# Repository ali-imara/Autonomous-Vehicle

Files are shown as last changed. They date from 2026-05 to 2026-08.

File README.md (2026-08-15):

# Autonomous Vehicle

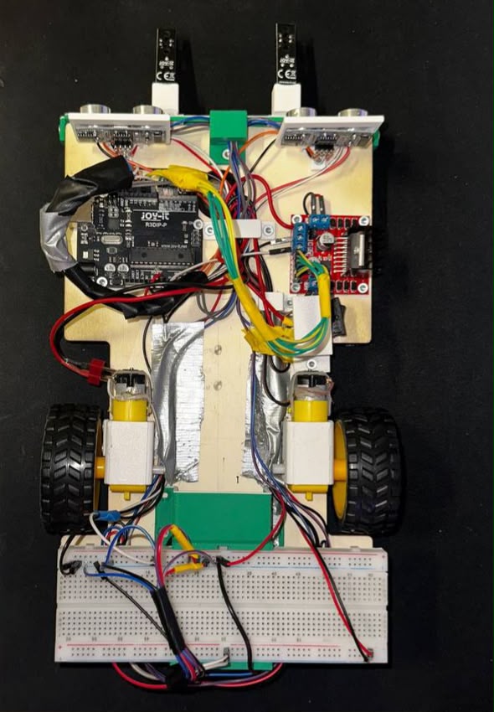
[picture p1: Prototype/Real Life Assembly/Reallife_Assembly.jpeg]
Project Overview


## Project Overview
This repository contains the engineering documentation, 3D mechanical designs, and control software for an autonomous prototype vehicle developed by Team D5. 

The primary focus of this project was to design, construct, and program a smart car capable of independent navigation and dynamic obstacle handling. The development process required the seamless integration of mechanical engineering, electronic hardware, and intelligent control algorithms using a comprehensive systems engineering methodology.

## Core Capabilities
The vehicle is designed to achieve the following autonomous objectives:
*   **Autonomous Navigation:** Follows a predefined track autonomously by utilizing dual infrared (IR) sensors to track the surrounding white surface and re-center on the black line.
*   **Early Obstacle Detection:** Recognizes obstructions in its path early by employing dual front-facing ultrasonic sensors.
*   **Dynamic Avoidance and Recovery:** Upon detecting an obstacle (≤ 18 cm), the vehicle executes an arc-based avoidance maneuver, safely bypasses the object, actively recovers the black line, and continues its route without manual intervention.
*   **Dual-Obstacle Handling:** As a special bonus objective, the system utilizes a persistent counter to track consecutive obstacles, triggering an automatic 180-degree spin to reverse course if the path is heavily blocked.

## Repository Structure
This repository is organized into the following directories to reflect the mechatronic development process:

*   📂 **`Arduino Code/`** 
    Contains the object-oriented C++ software, the finite state machine (FSM) control logic, and a technical README detailing the specific hardware pinouts and class architecture. 
*   📂 **`3D Design Parts/`** 
    Contains the SolidWorks part files and STEP files for the custom-designed chassis mounts, adjustable IR sensor slider, and component holders.
*   📂 **`Documentation/`**
    Contains the final engineering report, the project presentation, and task division documents.
*   📂 **`Prototype/`**
    Contains media and models from the physical build process, including the Tinkercad circuit simulation, circuit layouts, and real-life assembly photos.
*   📂 **`SYSML Diagrams/`**
    Contains the system modeling diagrams (Requirements, Activity, Sequence, etc.) used to map interactions between the sensors, Arduino, and motors prior to implementation.

## Project Team
**Team Members:**
*   Mohamed Awis (Team Leader)
*   Ali Abdelkhalek
*   Yassin Elhalawany

**Supervisors:** 
*   Prof. Dr. Stefan Henkler
*   Prof. Dr. Faezeh Pasandideh

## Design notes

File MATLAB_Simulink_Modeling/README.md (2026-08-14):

# MATLAB/Simulink Vehicle Modeling

This folder contains a MATLAB/Simulink extension of an autonomous
line-following vehicle project.

The simulation combines physical DC motor dynamics, differential-drive
vehicle kinematics, and a closed-loop line-following controller.

## DC Motor Model

The electrical motor dynamics are modeled as:

di/dt = (V - Ri - Keω) / L

The mechanical dynamics are:

dω/dt = (Kt i - bω - TL) / J

Motor torque is calculated using:

Tm = Kt i

Two motor models are used to represent the left and right drive wheels.

## Vehicle Model

Wheel angular velocities are converted into linear wheel velocities.

The differential-drive equations are:

v = (vR + vL) / 2

θ_dot = (vR - vL) / wheelDistance

Vehicle position is obtained from:

x_dot = v cos(θ)

y_dot = v sin(θ)

## Line-Following Controller

The lateral position reference is defined as:

y_ref = 0

The lateral error is:

e_y = y_ref - y

A feedback controller calculates the steering correction:

u = Ky e_y - Ktheta θ

The resulting motor voltage commands are:

V_R = Vbase + u

V_L = Vbase - u

Voltage saturation limits the motor commands to the available supply range.

## Validation

The DC motor model was first validated independently by comparing the
simulated current, torque, and angular velocity with analytical
steady-state and startup calculations.

The complete vehicle model was then tested with an initial lateral
offset. The controller successfully reduced the lateral position error
and drove the vehicle toward the reference line.

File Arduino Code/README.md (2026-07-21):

# D5 Autonomous Prototype Car Control Software
**Team D5 | Hochschule Hamm-Lippstadt**

## Overview
This folder contains the object-oriented C++ control software for the Team D5 autonomous prototype vehicle. The codebase allows the car to autonomously follow a track using infrared (IR) sensors, detect path obstructions early via dual ultrasonic sensors, and execute dynamic, arc-based avoidance maneuvers without manual intervention.

## Hardware Configuration
The vehicle is driven by an Arduino microcontroller and an L293D motor driver. The hardware pinout is defined in the code as follows:

| Component | Arduino Pin | Description |
| :--- | :--- | :--- |
| **Left Motor** | 9 (EN), 4 (IN1), 5 (IN2) | PWM speed control on pin 9 |
| **Right Motor** | 10 (EN), 6 (IN1), 7 (IN2) | PWM speed control on pin 10 |
| **Left IR Sensor** | 2 | Digital Input (LOW = White surface / HIGH = Black line) |
| **Right IR Sensor** | 3 | Digital Input (LOW = White surface / HIGH = Black line) |
| **Right Ultrasonic** | 8 (Trig), 11 (Echo) | Distance measurement |
| **Left Ultrasonic** | 12 (Trig), 13 (Echo) | Distance measurement |

## Software Architecture
The software is built using an Object-Oriented Programming (OOP) architecture to ensure modularity and readable control logic:
*   **Hardware Abstraction:** Custom `Motor`, `IRSensor`, and `UltrasonicSensor` classes abstract the low-level digital and analog pin manipulations.
*   **Core Controller (`Car`):** Manages the primary autonomous driving loop. It utilizes non-blocking timers (`millis()`) to continuously poll the ultrasonic sensors every 30 milliseconds without interrupting real-time line-following adjustments.
*   **Finite State Machine (FSM):** Obstacle avoidance is managed by the `AvoidState` enumeration. Upon detecting an object within the 18 cm threshold, the FSM transitions the vehicle through a sequence of specific states (`STOP_BEFORE_OBSTACLE`, `LEFT_ARC_AROUND`, `RIGHT_ARC_BACK`, `RECOVER_LINE`) to navigate safely.

## Key Features
*   **Surface-Based Line Following:** The vehicle continuously reads the white track surface. If either IR sensor detects the black line, the software instantly adjusts the differential motor speeds to re-center the vehicle.
*   **Smooth Arc Avoidance:** Instead of sharp, blocky turns, the vehicle bypasses obstacles using a calculated left arc, followed by a wider right arc to smoothly sweep back toward the original path.
*   **Dynamic Collision Prevention:** During an avoidance maneuver, if the lateral distance to an obstacle drops below 10 cm, the system dynamically sharpens the turning radius to prevent side-swiping.
*   **Bonus Objective (180-Degree Turn):** The system tracks consecutive obstacle detections. If a second obstacle is detected within a two-second cooldown window, the FSM triggers a `TURN_180` state. This bypasses standard avoidance, spins the vehicle completely around, and automatically recovers the line in the opposite direction. 

> **Safety Note:** Place the vehicle on the track prior to powering it on. The `setup()` function features a built-in 2-second delay (`while (millis() - startTime < 2000)`) to allow the user to clear their hands away before the drive motors engage.

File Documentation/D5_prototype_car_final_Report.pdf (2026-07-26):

1 | P a g e

## Prototyping Project Team D5

## 1. Introduction and Objectives

The development of autonomous vehicles is an interdisciplinary challenge that requires the seamless integration of mechanical engineering, electronic hardware, and intelligent control algorithms. This report details the engineering process of an autonomous prototype vehicle developed by Team D5 at Hochschule Hamm-Lippstadt. The primary focus of this project was to design, construct, and program a smart car capable of independent navigation and dynamic obstacle handling.

The core objectives of the project were defined as follows:

- Autonomous Navigation: The vehicle must successfully follow a predefined path autonomously using infrared (IR) sensor feedback.
- Early Obstacle Detection: The system must recognize obstructions in its path early by employing ultrasonic sensors.
- Dynamic Avoidance and Recovery: Upon detecting an obstacle, the vehicle must execute an avoidance maneuver, recover the line, and continue its operation without manual control.

To achieve these objectives, the project utilized a comprehensive systems engineering methodology. This approach progressed from initial SysML modeling and simulated testing to 3D mechanical design, software implementation, and iterative physical validation.

## 2. System Design and Engineering Approach

The autonomous vehicle was developed using an integrated mechatronic design process covering requirements, system modeling, mechanical design, electronics, control software, simulation, and physical validation. The main objectives were autonomous black-line following, obstacle detection and avoidance, line reacquisition, and stable vehicle motion.

### 2.1 System Modeling

Requirements, use case, activity, sequence, and package diagrams were created to describe the system from complementary viewpoints. The requirements diagram defined and traced the main functions to the corresponding hardware, while the activity diagram described the operational logic. The remaining diagrams supported functional interaction, system organization, and component communication.

The requirements model decomposed the overall autonomous-driving objective into line detection, obstacle detection, motion control, speed optimization, and obstacle avoidance. Two infrared sensors were assigned to line tracking, two ultrasonic sensors to obstacle detection, and the motor-control subsystem to the two drive motors. This provided clear traceability between system requirements and physical implementation.

### 2.2 Engineering Implementation

The activity model defined the main control sequence: initialize sensors, read sensor data, follow the line, detect an obstacle, execute an avoidance maneuver, reacquire the line, and resume normal operation. This logic was implemented in software using modular classes for the motors, infrared sensors, ultrasonic sensors, and vehicle controller, together with explicit states for obstacle handling and recovery.

Mechanical development was performed in SolidWorks using a component-by-component approach before assembling the complete vehicle model. This allowed the positions of the motors, wheels, sensors, controller, and supporting parts to be checked before physical integration. The design was refined iteratively because sensor placement, vehicle geometry, motor response, and control parameters directly affected overall performance.

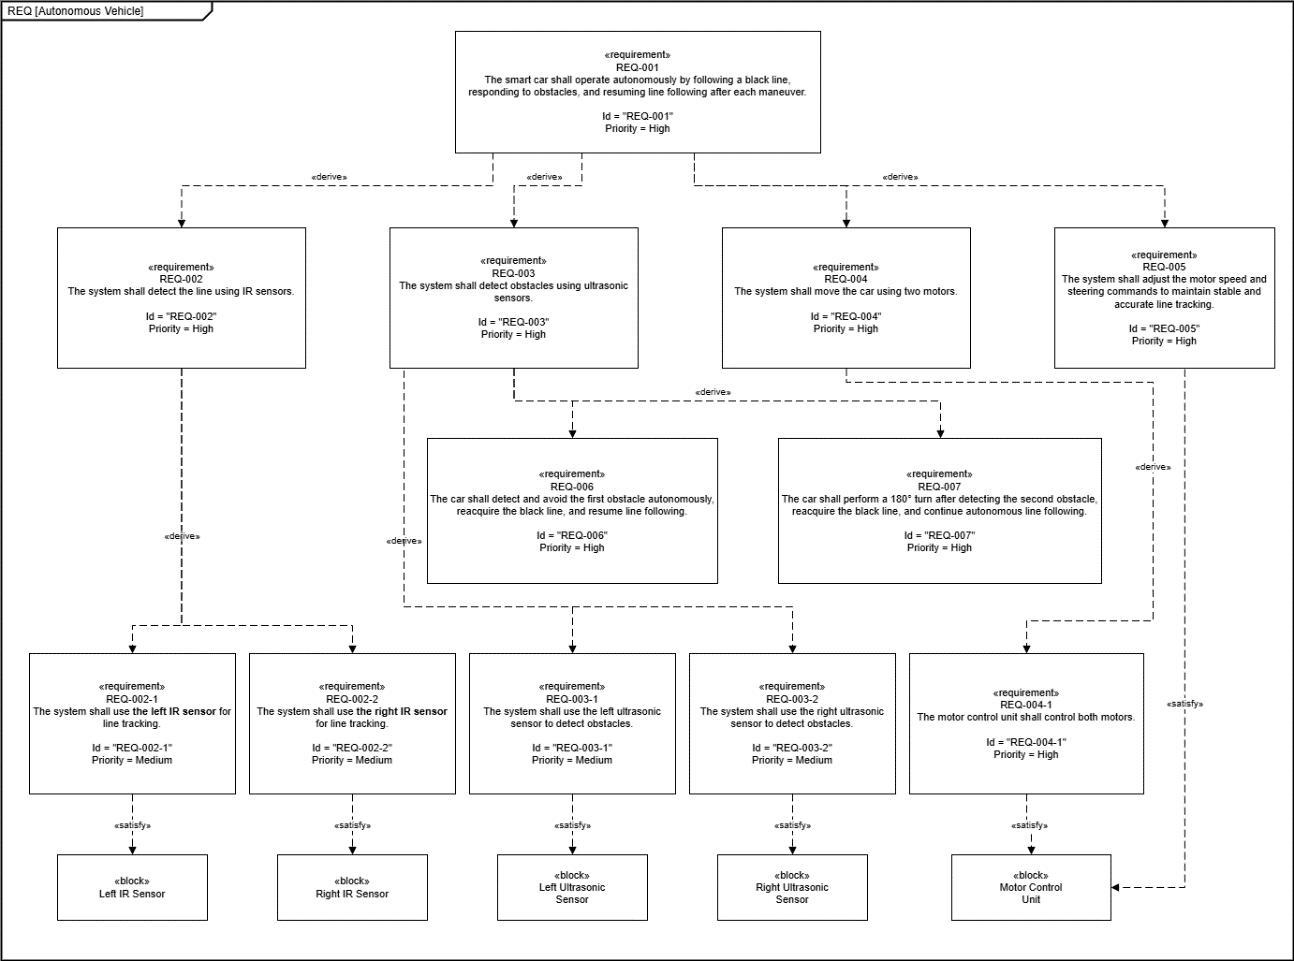
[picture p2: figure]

2 | P a g e

Fig. 1. Requirements model linking the autonomous-driving objectives to line sensing, obstacle sensing, motor control, and speed control.

## 3. Hardware and Software Implementation

### 3.1 Hardware Integration

The autonomous prototype car was controlled by an Arduino-based microcontroller. Its main hardware components included a breadboard, two motor-driver units, two IR sensors, two ultrasonic sensors, and a battery. The motor drivers controlled the speed and direction of the left and right motors, while the breadboard supported the electrical connections and power distribution.

The two IR sensors were installed at the front and close to the ground to distinguish
between the black line and the white track surface. The ultrasonic sensors were also positioned at the front to measure the distance to obstacles. Using two ultrasonic sensors increased the detection area and allowed objects approaching either side of the car to be recognized.

Custom component holders were designed using SolidWorks. Their positions were selected according to the function of each component and the available space on the chassis. The holders secured the sensors while allowing their positions to be adjusted. This arrangement also improved cable management: each wire was routed toward its corresponding component, reducing tangled or overlapping connections and making the electrical system easier to assemble, inspect, and troubleshoot.

### 3.2 Software Design and Control Logic

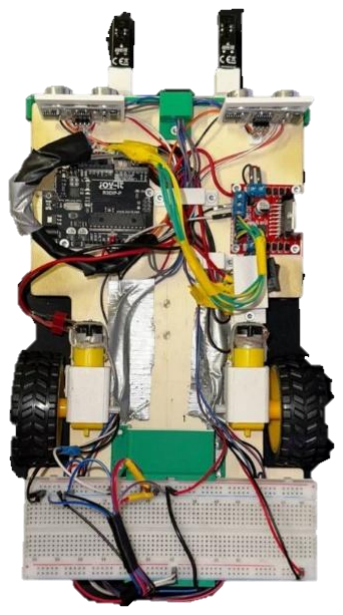
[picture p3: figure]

The vehicle’s control software was developed in C++ utilizing an object-oriented architecture to ensure modularity and ease of troubleshooting. Dedicated classes (Motor, IRSensor, and UltrasonicSensor) were constructed to abstract the low-level pin manipulations and standardize the interface between the hardware and the main control logic.

3 | P a g e

The core autonomous loop operates on a non-blocking framework, utilizing the microcontroller's internal timer (millis()) rather than standard delay functions. This allows the system to continuously poll the ultrasonic sensors at 30-millisecond intervals without interrupting the real-time line-following adjustments.

During standard operation, the Car class governs navigation. The system reads the track surface via the dual IR sensors; when both detect the white surface, the vehicle drives forward. If one sensor detects the black line, the software dynamically adjusts the differential motor speeds to re-center the vehicle, correcting its trajectory.

To handle obstructions, the software implements a Finite State Machine (FSM) controlled by the AvoidState enumeration. When the ultrasonic sensors detect an object within the 18 cm threshold, the system transitions from the IDLE state into an avoidance sequence:

- STOP_BEFORE_OBSTACLE: Halts the DC motors to prevent collision.
- LEFT_ARC_AROUND & RIGHT_ARC_BACK: Executes carefully timed, differential motor speeds to bypass the object and sweep back toward the original path. A dynamic distance check is integrated here; if the lateral distance to the object drops below 10 cm, the system temporarily sharpens the turn radius to prevent side-swiping.
- Line Recovery (SEARCH_LINE & RECOVER_LINE): Instead of relying solely on dead reckoning, the FSM actively polls the IR sensors while spinning. The loop breaks at the exact millisecond a sensor touches the black line, pausing briefly to let the chassis settle before resuming forward motion.

enum AvoidState {

IDLE, STOP_BEFORE_OBSTACLE, LEFT_ARC_AROUND, RIGHT_ARC_BACK, SEARCH_LINE, RECOVER_LINE, TURN_180 };

void handleObstacleAvoidance() {

unsigned long elapsed = millis() - avoidTimer;

switch (avoidState) {

case STOP_BEFORE_OBSTACLE:

stop();

if (elapsed > STOP_TIME) {

avoidState = LEFT_ARC_AROUND;

avoidTimer = millis();

}

break;

case LEFT_ARC_AROUND:

if (rightSonar.getDistance() > 0 &&

rightSonar.getDistance() < 10) spinLeft();

else arcLeft();

if (elapsed > LEFT_ARC_TIME) {

avoidState = RIGHT_ARC_BACK;

avoidTimer = millis();

}

break;

case RIGHT_ARC_BACK:

arcRight();

if (elapsed > 150 && blackLineDetected()) {

delay(250);

spinLeft();

while (!blackLineDetected()) {} // Spin

stop();

avoidState = RECOVER_LINE;

}

break;

case TURN_180:

leftMotor.forward(0); rightMotor.forward(65);

if (elapsed > 1400 && blackLineDetected()) {

stop();

avoidState = RECOVER_LINE;

isTurning = false;

}

break;

}

}

4 | P a g e

Additionally, to fulfill a bonus objective, a dual-obstacle tracking mechanism was implemented. The software maintains a persistent counter for detected obstacles. To ensure a single object is not counted multiple times during a maneuver, a two-second cooldown is enforced between valid detections. Once the system registers a second distinct obstacle, it triggers a TURN_180 state, bypassing the standard avoidance arc to spin the vehicle completely around and automatically recover the line in the opposite direction.

## 4. Simulation and Testing Results

### 4.1 Circuit Simulation

The electronic architecture was first modeled in TinkerCAD to verify the main connections and controller interfaces before complete physical testing. The model included an Arduino Uno, an L293D motor driver, two DC motors, two infrared sensors, two HC-SR04 ultrasonic sensors, and the power circuitry.

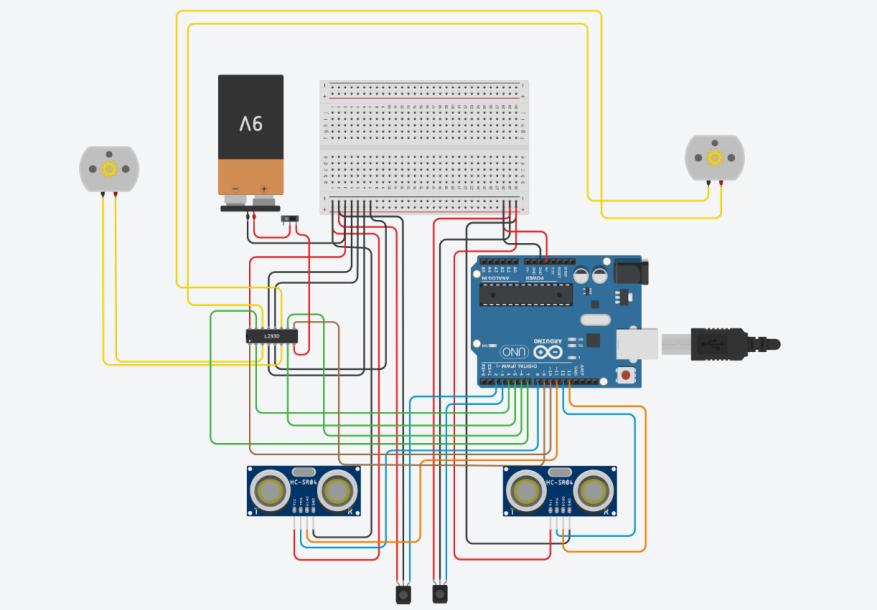
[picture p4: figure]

Fig. 2. TinkerCAD circuit model is used to verify the controller, sensors, motor driver, and drive motors.

Parameter | Value | Purpose
Battery supply | 9 V | External circuit supply
Controller / sensor logic | 5 V | Arduino and sensor operating level
Obstacle detection threshold | ≤ 18 cm | Triggers avoidance sequence
Close-obstacle correction | < 10 cm | Applies stronger steering correction

Table 1. Key electrical and distance parameters used in the implemented system.

### 4.2 Physical Testing

Testing was divided into two main tasks. In Task 1, the vehicle was required to follow the black line autonomously using the two infrared sensors. Motor speed and steering parameters were tuned through repeated runs to improve tracking stability and reduce excessive oscillation. Vehicle speed was determined experimentally from travelled distance and elapsed time.

In Task 2, an obstacle was placed in the vehicle path. When the measured distance reached the defined threshold, normal line following was interrupted and the vehicle executed a programmed avoidance sequence: stop, move

5 | P a g e

around the obstacle, return toward the original path, detect the black line again, and resume line following. A dedicated search-and-recovery state was included if the line was not immediately required.

The evaluation therefore focused on three performance indicators: line-following stability, vehicle speed, and successful obstacle avoidance followed by line reacquisition. Together, circuit simulation and physical testing provided progressive validation from subsystem integration to complete autonomous operation.

## 5. Challenges Encountered and Solutions

### 5.1 IR Sensor Position and Line-Following Method

The first challenge resulted from the mechanical design of the IR sensor holders. The holders were mounted inside an adjustable slider at the front of the chassis. Although the slider allowed their horizontal positions to be changed, it placed the sensors slightly too far above the ground. This made it difficult to position both sensors directly over the black line and obtain consistent readings.

To solve this problem, the control method was changed from following the black line directly to following the surrounding white surface. When both sensors detect white, the car moves forward with the black line centred between them. If one sensor reaches the black line, the program corrects the direction. This method improved stability and allowed the car to move faster when properly centered.

### 5.2 Speed and Detection-Distance Optimization

Choosing an appropriate driving speed was another challenge. A high speed produced good performance on straight sections, but the car sometimes left the track during sharp turns because the system could not correct its direction quickly enough. Different motor speeds were therefore tested on straight sections, normal curves, and sharp turns. The final values provided a suitable balance between speed and steering response.

The ultrasonic detection distance also required calibration. A large range caused the car to react to nearby walls or people beside the track, whereas a very short range caused late detection and left insufficient space for avoidance. After repeated testing, the distance was set to 18 cm. This reduced false detections while still providing enough space to begin the avoidance maneuver. A sharper correction was added when the distance fell below 10 cm.

### 5.3 Obstacle Avoidance and Line Recovery

Several avoidance methods were tested. One early approach used a sequence of timed left and right movements, while another produced a V-shaped path. These methods involved sharp direction changes and were inconsistent because small differences in motor speed, starting position, and battery level affected the path. The car could therefore collide with the obstacle while passing it or while returning to the line.

The final solution used a smoother arc-based maneuver. The car stops, follows a left arc around the obstacle, and then follows a longer right arc toward the track. Different speeds are applied to the two motors to form each curve. When the line is detected again, the car crosses it slightly and rotates until the correct position is recovered.

These improvements were achieved through continuous testing and observation. Each result was analyzed to determine whether the problem originated from the mechanical design, sensor configuration, motor speed, or software logic. This iterative process significantly improved the reliability and consistency of the prototype.

6 | P a g e

## 6. Conclusions and Future Improvements

### 6.1 Conclusions

The project successfully yielded a fully functional autonomous prototype vehicle by integrating a custom 3D-printed mechanical structure, sensor arrays, an Arduino logic controller, and motor drivers into a single cohesive unit. Through structured system engineering and continuous testing, the initial theoretical models were effectively translated into a reliable physical system.

A primary learning outcome of this project was understanding the critical interplay between mechanical component placement, software logic, and speed optimization. Physical testing directly influenced the final vehicle behaviour; for instance, evaluation results prompted a shift in the line-following concept and refined the timing sequence for the arc-based obstacle avoidance maneuvers. Ultimately, the vehicle consistently demonstrated the ability to track a path, dynamically maneuver around obstacles, and recover its route autonomously.

### 6.2 Future Improvements

While the current prototype meets all primary project requirements, several areas have been identified for future enhancement to increase the vehicle's speed, precision, and overall reliability:

- PID Control Implementation: Upgrading the steering logic to a Proportional-Integral-Derivative (PID) controller would allow for smoother trajectory corrections and reduce oscillations during active line following.
- Expanded Sensor Array: Incorporating additional IR sensors would improve surface resolution, facilitating better and faster line recovery after an avoidance maneuver.
- Hardware Upgrades: Integrating an enhanced motor control driver would provide finer speed regulation and improved handling of the DC motors.
- Custom Printed Circuit Board (PCB): Replacing the prototype breadboard with a custom-specified PCB would significantly improve wiring reliability, reduce electrical noise, and condense the electronic footprint of the project.

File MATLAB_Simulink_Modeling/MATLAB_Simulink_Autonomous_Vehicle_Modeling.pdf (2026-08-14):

# MATLAB/Simulink Modeling

Mathematical Model of the Differential-Drive Vehicle and Line-Following Controller:

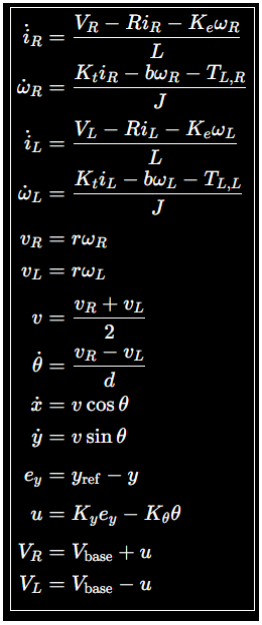
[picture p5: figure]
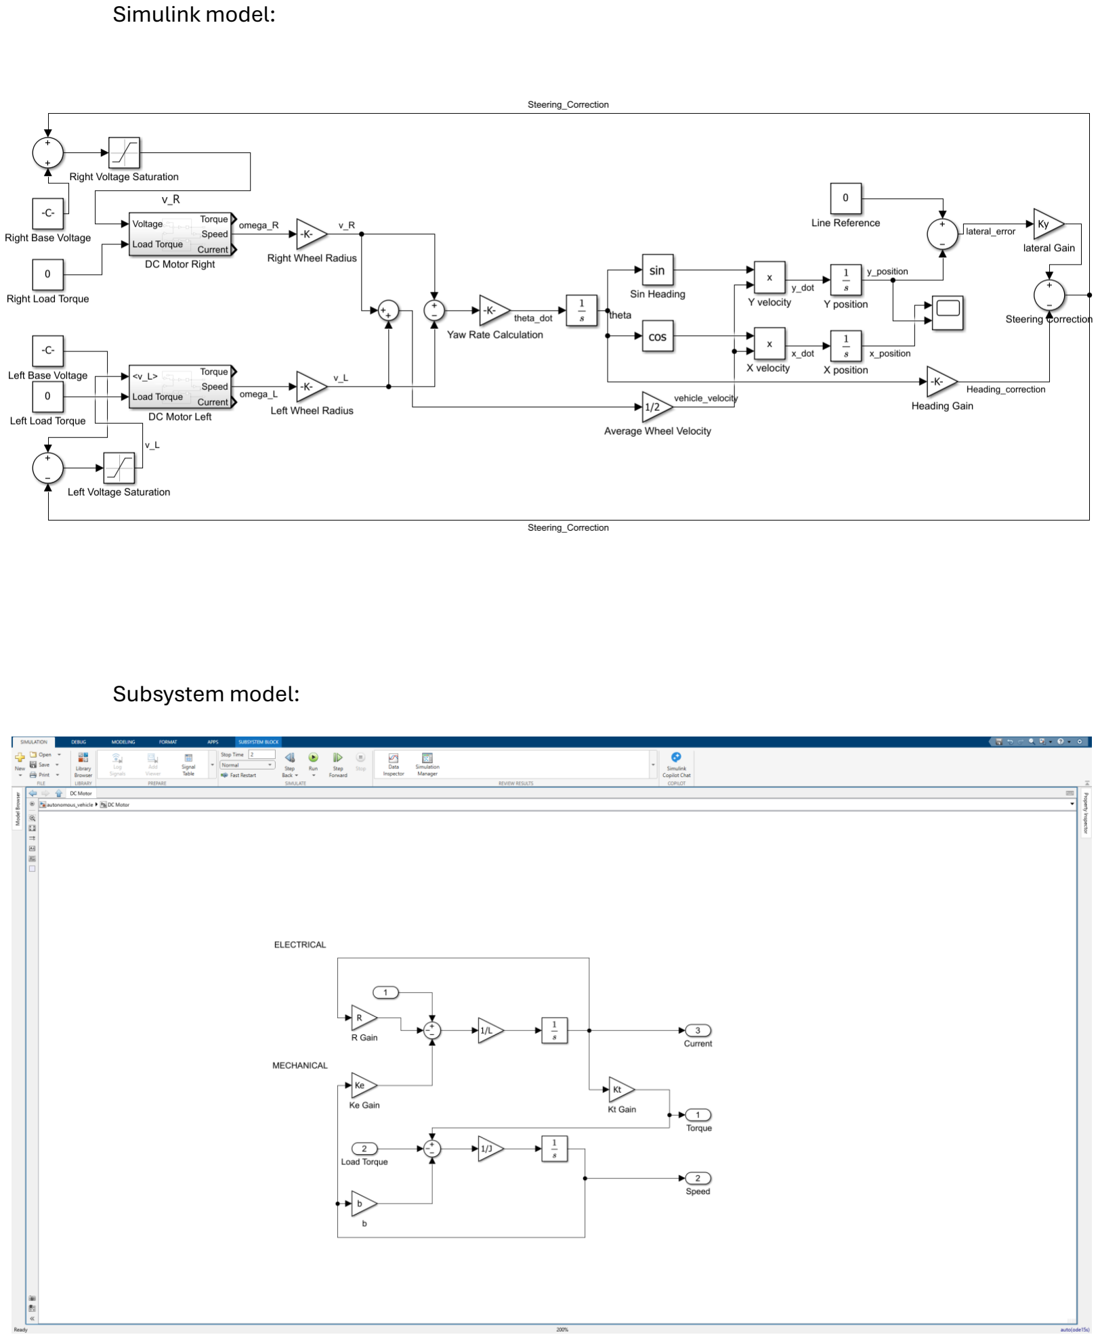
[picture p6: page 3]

Simulink model:

Subsystem model:

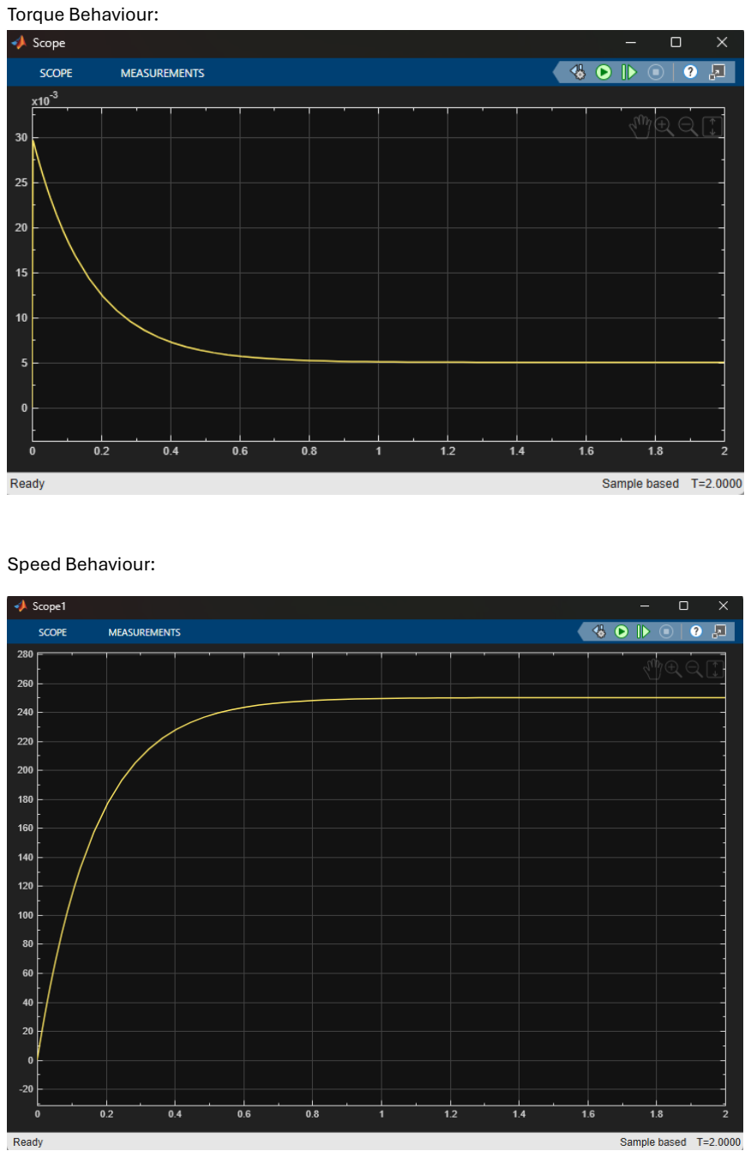
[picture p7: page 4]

Torque Behaviour:

Speed Behaviour:

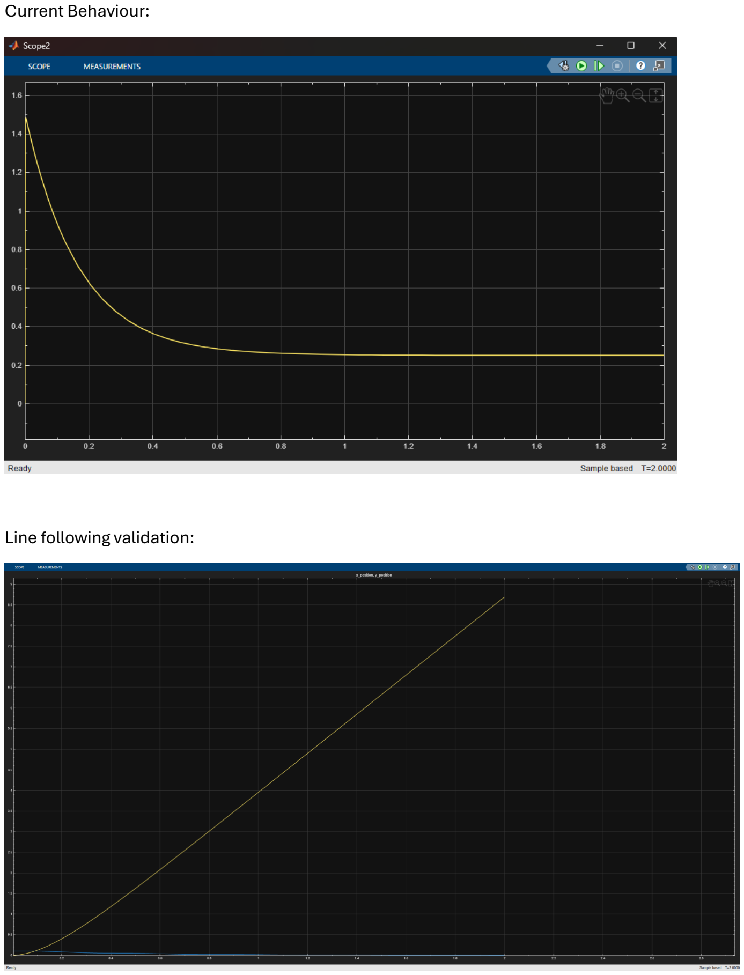
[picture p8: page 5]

Current Behaviour:

Line following validation:

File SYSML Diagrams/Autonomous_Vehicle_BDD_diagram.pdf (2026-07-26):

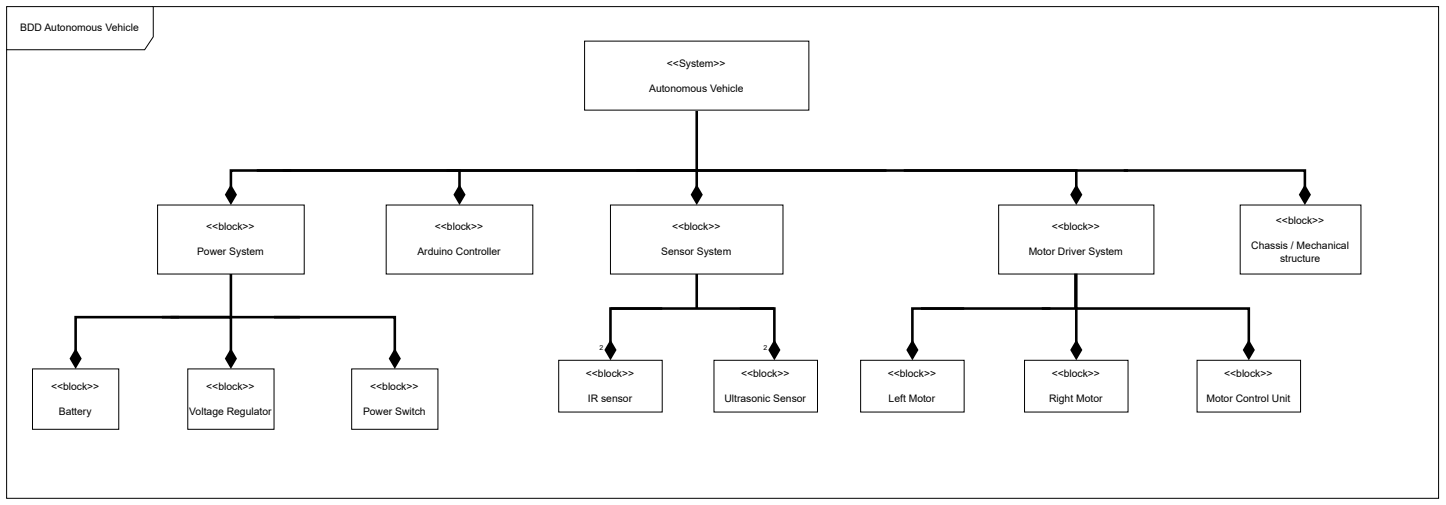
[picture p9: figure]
<<System>>; Autonomous Vehicle; <<block>>; Power System; Arduino Controller; Sensor System; Motor Driver System; Chassis / Mechanical structure; Battery; Voltage Regulator; Power Switch; IR sensor; Ultrasonic Sensor; Left Motor; Right Motor; BDD Autonomous Vehicle; Motor Control Unit

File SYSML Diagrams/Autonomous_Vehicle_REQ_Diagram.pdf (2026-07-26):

REQ [Autonomous Vehicle]

«requirement»
REQ-001
The smart car shall operate autonomously by following a black line, responding to obstacles, and resuming line following after each maneuver.

Id = "REQ-001"
Priority = High

«requirement»
REQ-002
The system shall detect the line using IR sensors.

Id = "REQ-002"
Priority = High

«requirement»
REQ-003
The system shall detect obstacles using ultrasonic sensors.

Id = "REQ-003"
Priority = High

«requirement»
REQ-004
The system shall move the car using two motors.

Id = "REQ-004"
Priority = High

«requirement»
REQ-005
The system shall adjust the motor speed and steering commands to maintain stable and accurate line tracking.

Id = "REQ-005"
Priority = High

«requirement»
REQ-006
The car shall detect and avoid the first obstacle autonomously, reacquire the black line, and resume line following.

Id = "REQ-006"
Priority = High

«requirement»
REQ-007
The car shall perform a 180° turn after detecting the second obstacle, reacquire the black line, and continue autonomous line following.

Id = "REQ-007"
Priority = High

«requirement»
REQ-002-1
The system shall use the left IR sensor for line tracking.

Id = "REQ-002-1"
Priority = Medium

«requirement»
REQ-002-2
The system shall use the right IR sensor for line tracking.

Id = "REQ-002-2"
Priority = Medium

«requirement»
REQ-003-1
The system shall use the left ultrasonic sensor to detect obstacles.

Id = "REQ-003-1"
Priority = Medium

«requirement»
REQ-003-2
The system shall use the right ultrasonic sensor to detect obstacles.

Id = "REQ-003-2"
Priority = Medium

«requirement»
REQ-004-1
The motor control unit shall control both motors.

Id = "REQ-004-1"
Priority = High

«block»
Left IR Sensor

«block»
Right IR Sensor

«block»
Left Ultrasonic
Sensor

«block»
Right Ultrasonic
Sensor

«block»
Motor Control
Unit
«derive» | «derive» | «derive»
«derive» | «derive»

«derive»

«derive»

«satisfy» | «satisfy» | «satisfy» | «satisfy» | «satisfy»

«satisfy»

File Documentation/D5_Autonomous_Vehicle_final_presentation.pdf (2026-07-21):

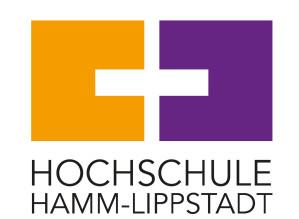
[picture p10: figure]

# Autonomous Prototype Car Project

## (Team D5)

## Team members:

Ali Abdelkhalek
Mohamed Awis
Yassin Elhalawany

## Supervisors:

Prof/ Dr Stefan Henkler
Prof/ Dr Faezeh Pasandideh

# Project Overview

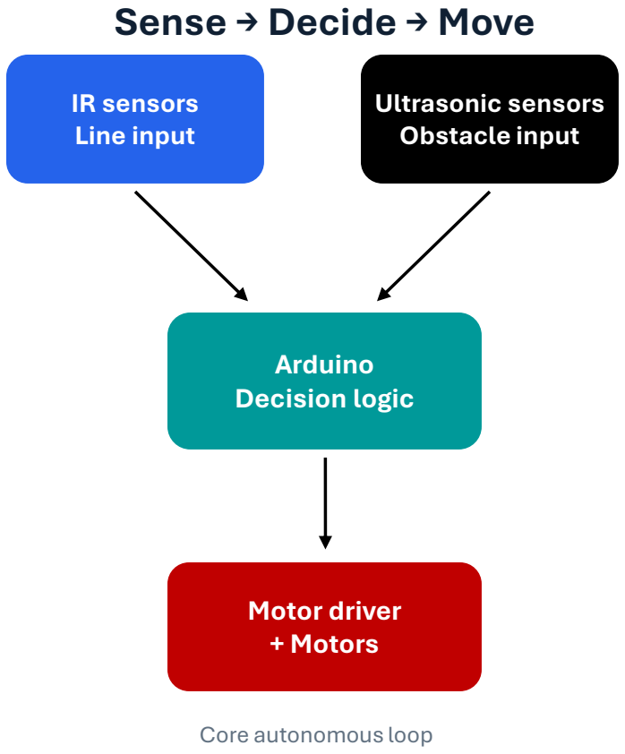
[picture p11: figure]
Sense → Decide → Move; IR sensors Line input; Ultrasonic sensors Obstacle input; Arduino Decision logic; Motor driver + Motors; Core autonomous loop

From system engineering to real-time line following and obstacle avoidance
Project goal
- Follow a path autonomously using IR sensor
feedback.
- Detect obstacles early using an ultrasonic
sensor.
- Avoid the obstacle, recover the line, and continue without manual control.

Engineering path
Req. | SysML | Sim+ 3D | Code | Test

02

03

# System Engineering Using SysML

We modeled the prototype before implementation so the behavior, structure, and interfaces were clear.

SysML
System Model

Requirement
What the car must do

BDD / IBD
Blocks, interfaces, signal + power flow

Activity
Power on → sensing → decision → motion

Sequence
Interaction order between user, sensors, Arduino, motors

Package
Organized hardware, software, sensing, control, movement

SysML connected the idea to the real implementation and reduced trial-and-error during integration.

# TinkerCAD Simulation & 3D Design

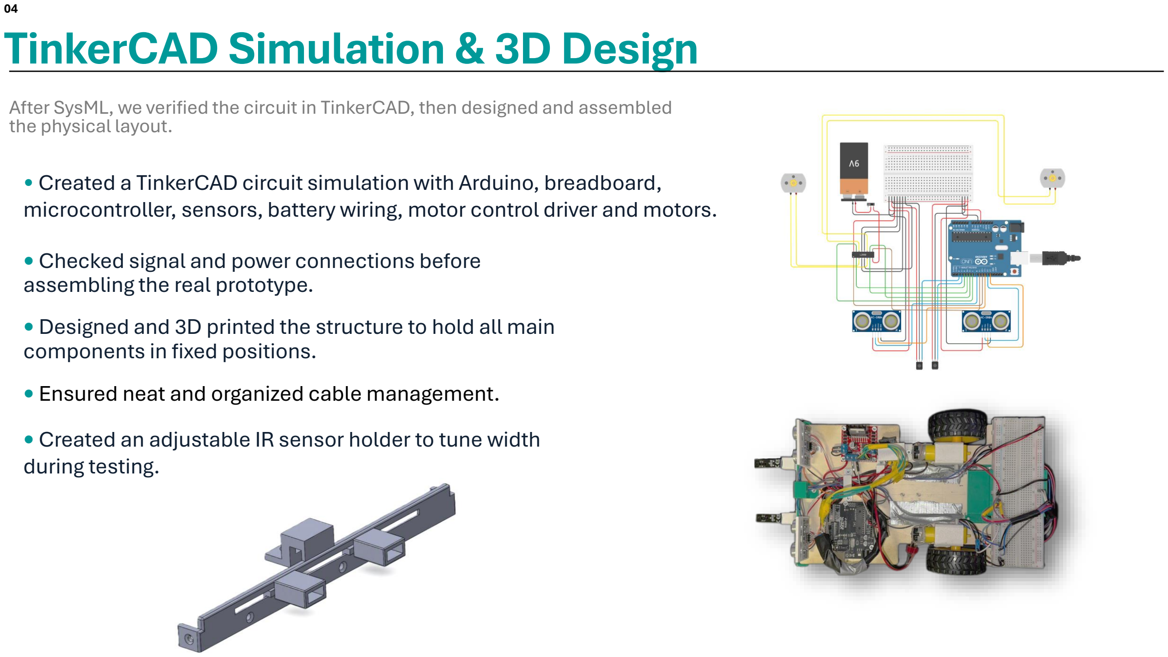
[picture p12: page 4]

04

After SysML, we verified the circuit in TinkerCAD, then designed and assembled
the physical layout.
- Created a TinkerCAD circuit simulation with Arduino, breadboard, microcontroller, sensors, battery wiring, motor control driver and motors.
- Checked signal and power connections before
assembling the real prototype.
- Designed and 3D printed the structure to hold all main
components in fixed positions.
- Ensured neat and organized cable management.
- Created an adjustable IR sensor holder to tune width during testing.

05

# Milestone 1: Line Following

We adapted the software concept to match the real sensor spacing of our 3D design.

IR sensors could not be placed very close Use white-surface readings to adjust the

Line-following control loop

Result The final logic matched our mechanical design better and made line following more effective with higher speeds recording fastest lap in our group

06

# Milestone 2: Obstacle Avoidance

We added an avoidance behavior that temporarily takes priority over normal line following.

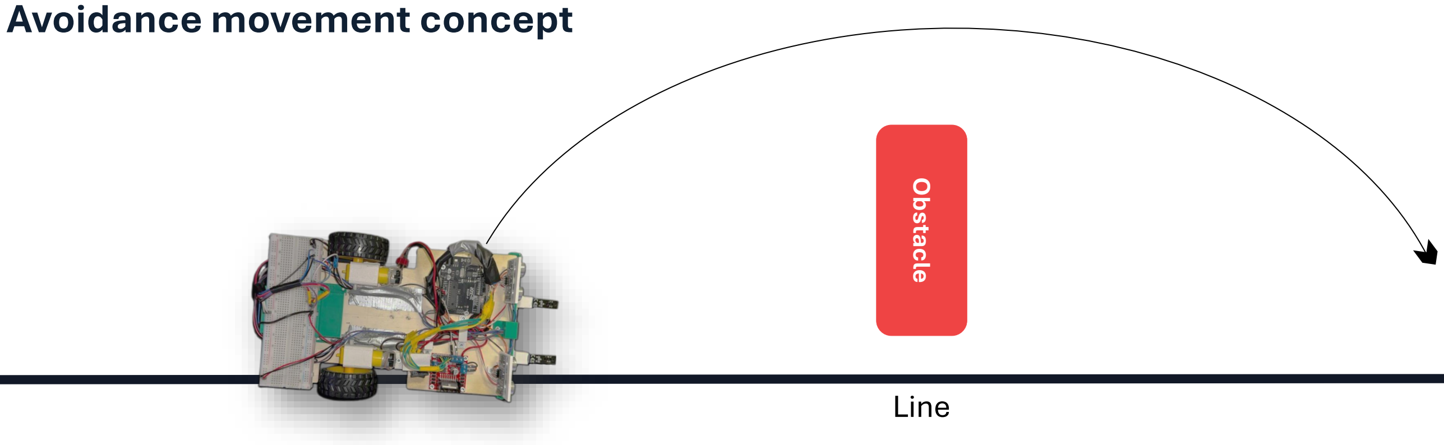
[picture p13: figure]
Avoidance movement concept; LineObstacle

Avoidance is not only passing the obstacle, but it must also recover the line successfully.

07

# Conclusion: What We Achieved and Learned

A complete prototype was built through design, modeling, implementation, and testing.

Achieved
Integrated 3D design, sensors, Arduino logic, motor driver, and
movement into one autonomous prototype.

Main learning
Mechanical design, component placement, code logic and speed optimization.

Evaluation value
Testing changed our line-following concept and improved the obstacle-avoidance timing.

Future
improvements

PID control
Smoother correction

More IR sensors
Better line recovery

Enhanced motor control
driver

Specified PCB
for the project

# Thank you for your attention

We are happy to answer your questions!

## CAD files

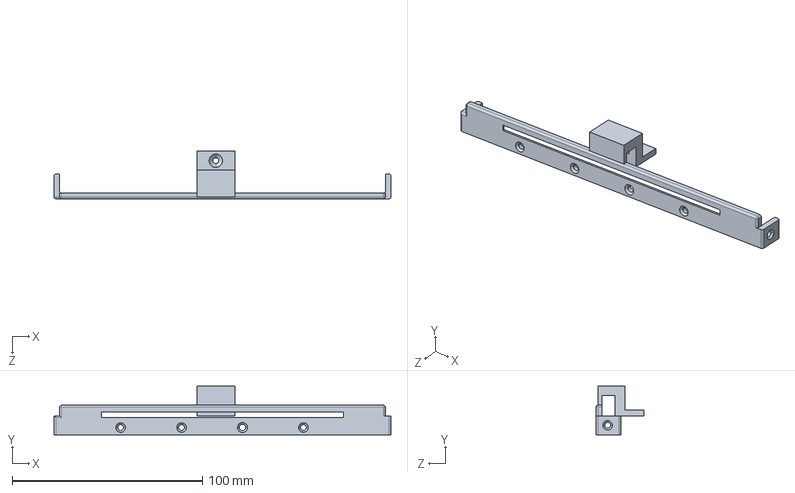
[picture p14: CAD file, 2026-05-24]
3D Design Parts/D5 - Slider track full part.STEP
177.0 x 25.6 x 25.0 mm

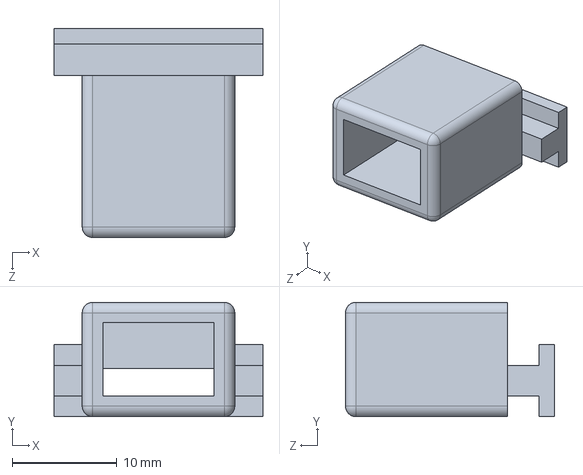
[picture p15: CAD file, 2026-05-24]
3D Design Parts/D5 - IR slider for the track.STEP
20.0 x 10.9 x 20.0 mm

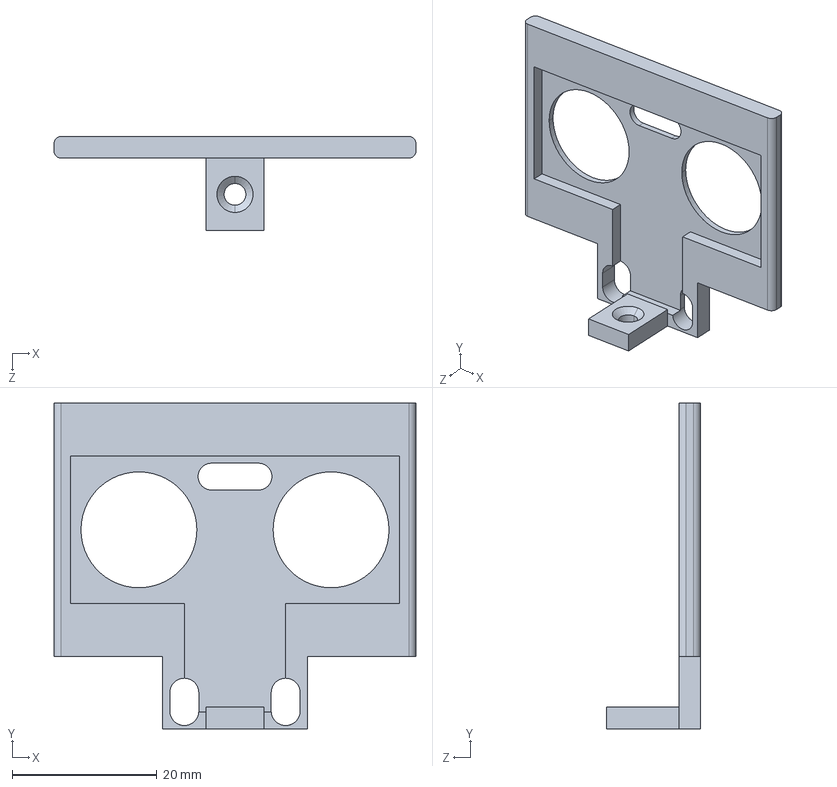
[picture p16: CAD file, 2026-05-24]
3D Design Parts/D5 - Ultrasonic Holder.STEP
50.0 x 45.0 x 13.0 mm

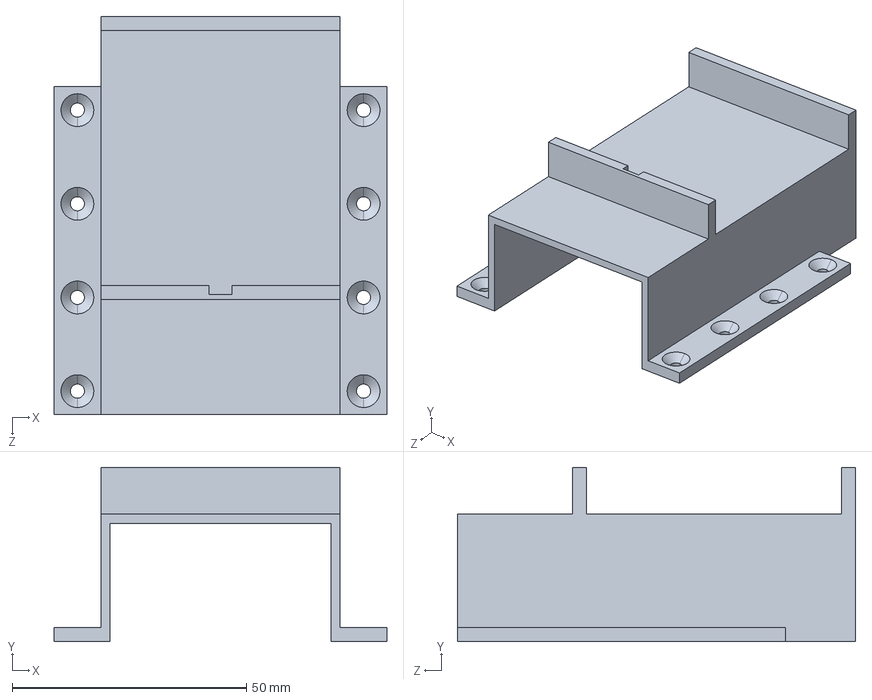
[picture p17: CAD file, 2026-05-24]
3D Design Parts/D5 - Battery and Breadboard Holder.STEP
71.1 x 37.2 x 85.0 mm

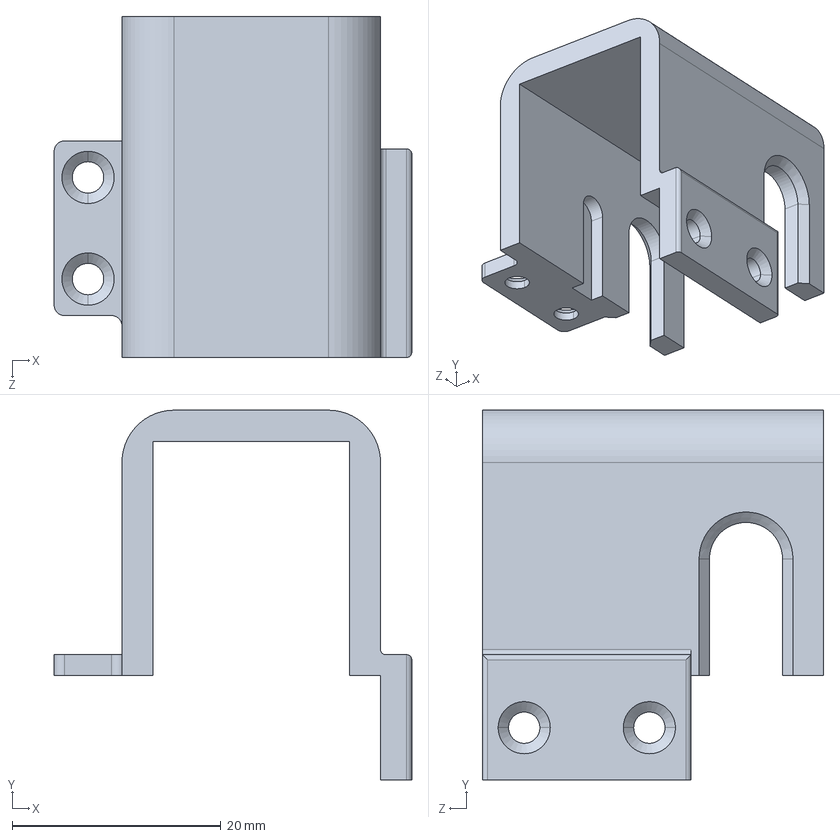
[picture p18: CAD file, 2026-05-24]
3D Design Parts/D5 - Motor Holder Right.STEP
34.3 x 35.4 x 32.7 mm

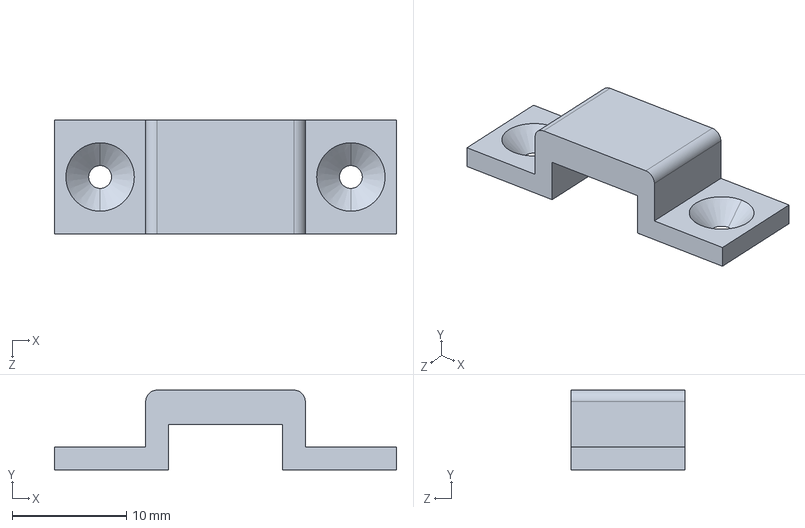
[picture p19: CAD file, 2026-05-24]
3D Design Parts/D5 - Wires Track.STEP
30.0 x 7.00 x 10.0 mm

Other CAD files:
3D Design Parts/D5 - Motor Holder Left.STEP

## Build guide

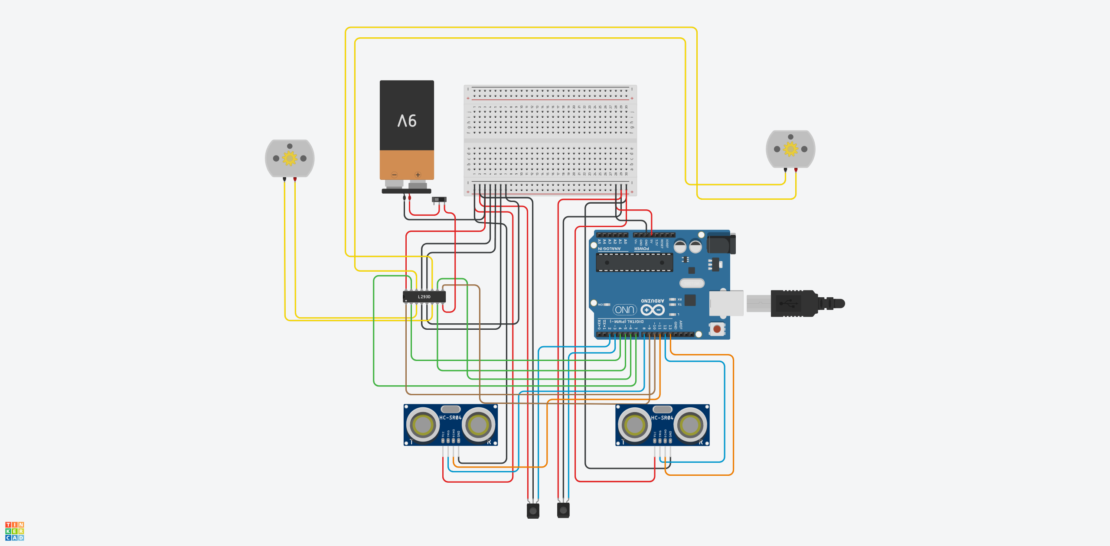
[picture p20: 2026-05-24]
Prototype/Simulation (TinkerCAD)/D5_Autonomous_Vehicle_TinkerCAD Assembly_Design.png

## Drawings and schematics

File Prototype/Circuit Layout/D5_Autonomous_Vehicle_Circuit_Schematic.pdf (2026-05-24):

A

1 | 2 | 3 | 4 | 5 | 6

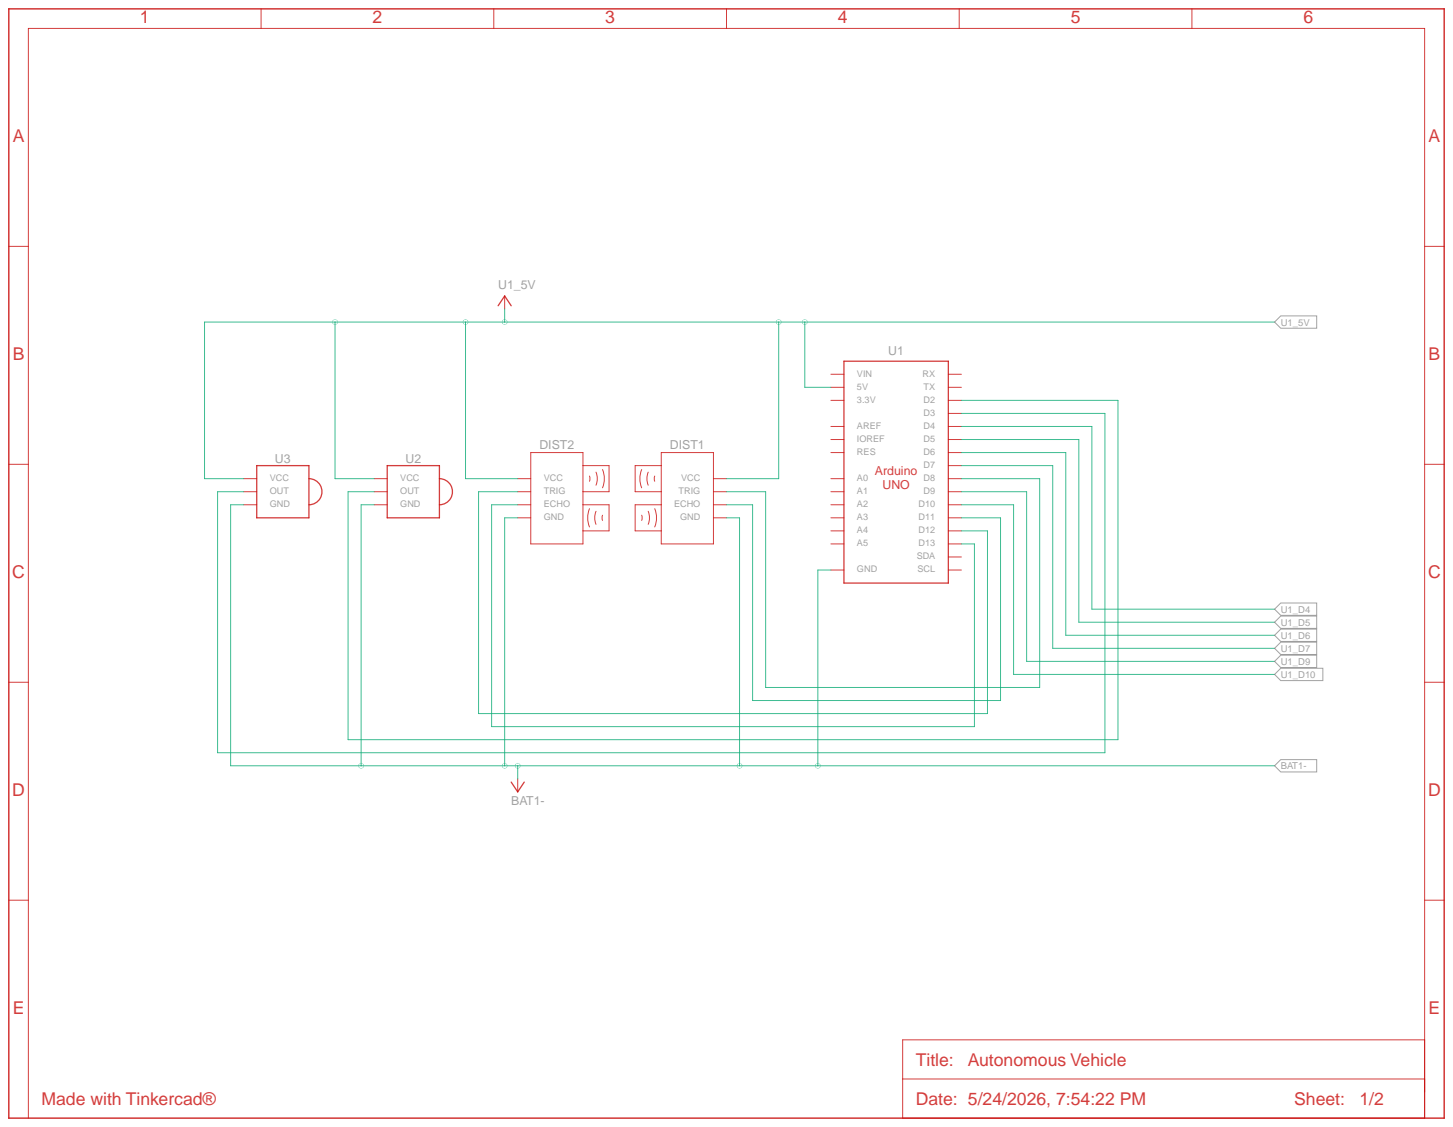
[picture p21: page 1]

A

1 | 2 | 3 | 4 | 5 | 6

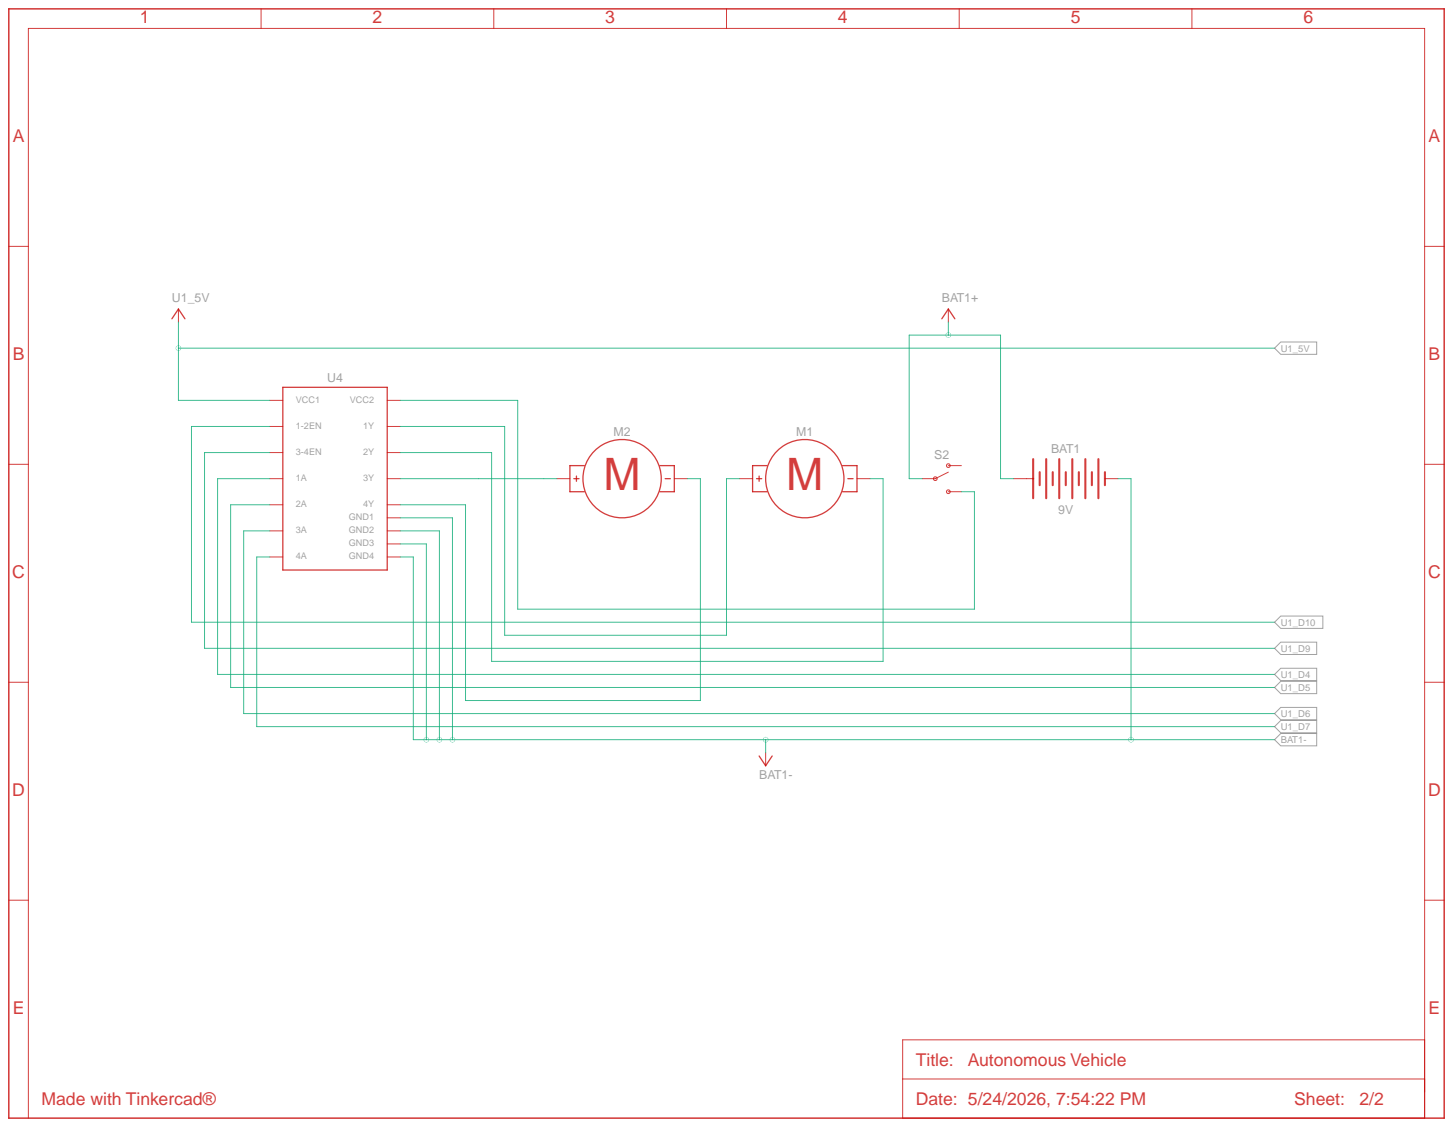
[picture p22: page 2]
Date: 5/24/2026, 7:54:22 PM; Sheet: 2/2; GND1 GND2; VCC1; VCC2; GND3 GND4; BAT1; BAT1+; BAT1-

Title: Autonomous Vehicle

Made with Tinkercad®

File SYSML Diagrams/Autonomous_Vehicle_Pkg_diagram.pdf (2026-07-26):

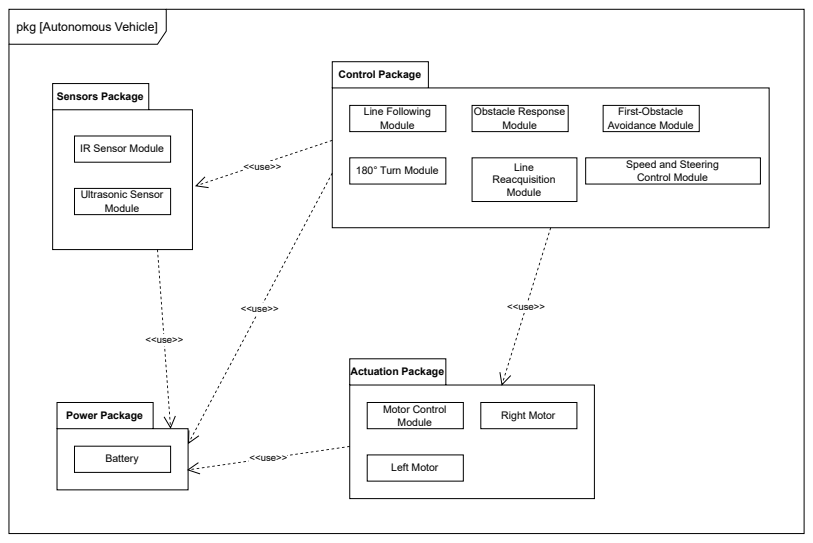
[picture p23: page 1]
Power Package; Battery; Control Package; Line Following Module; Obstacle Response Module; First-Obstacle Avoidance Module; 180° Turn Module; Line; Reacquisition Module; Actuation Package; Motor Control; Module; Right Motor; Left Motor; Sensors Package; Ultrasonic Sensor Module; <<use>>

pkg [Autonomous Vehicle]

IR Sensor Module

Speed and Steering
Control Module

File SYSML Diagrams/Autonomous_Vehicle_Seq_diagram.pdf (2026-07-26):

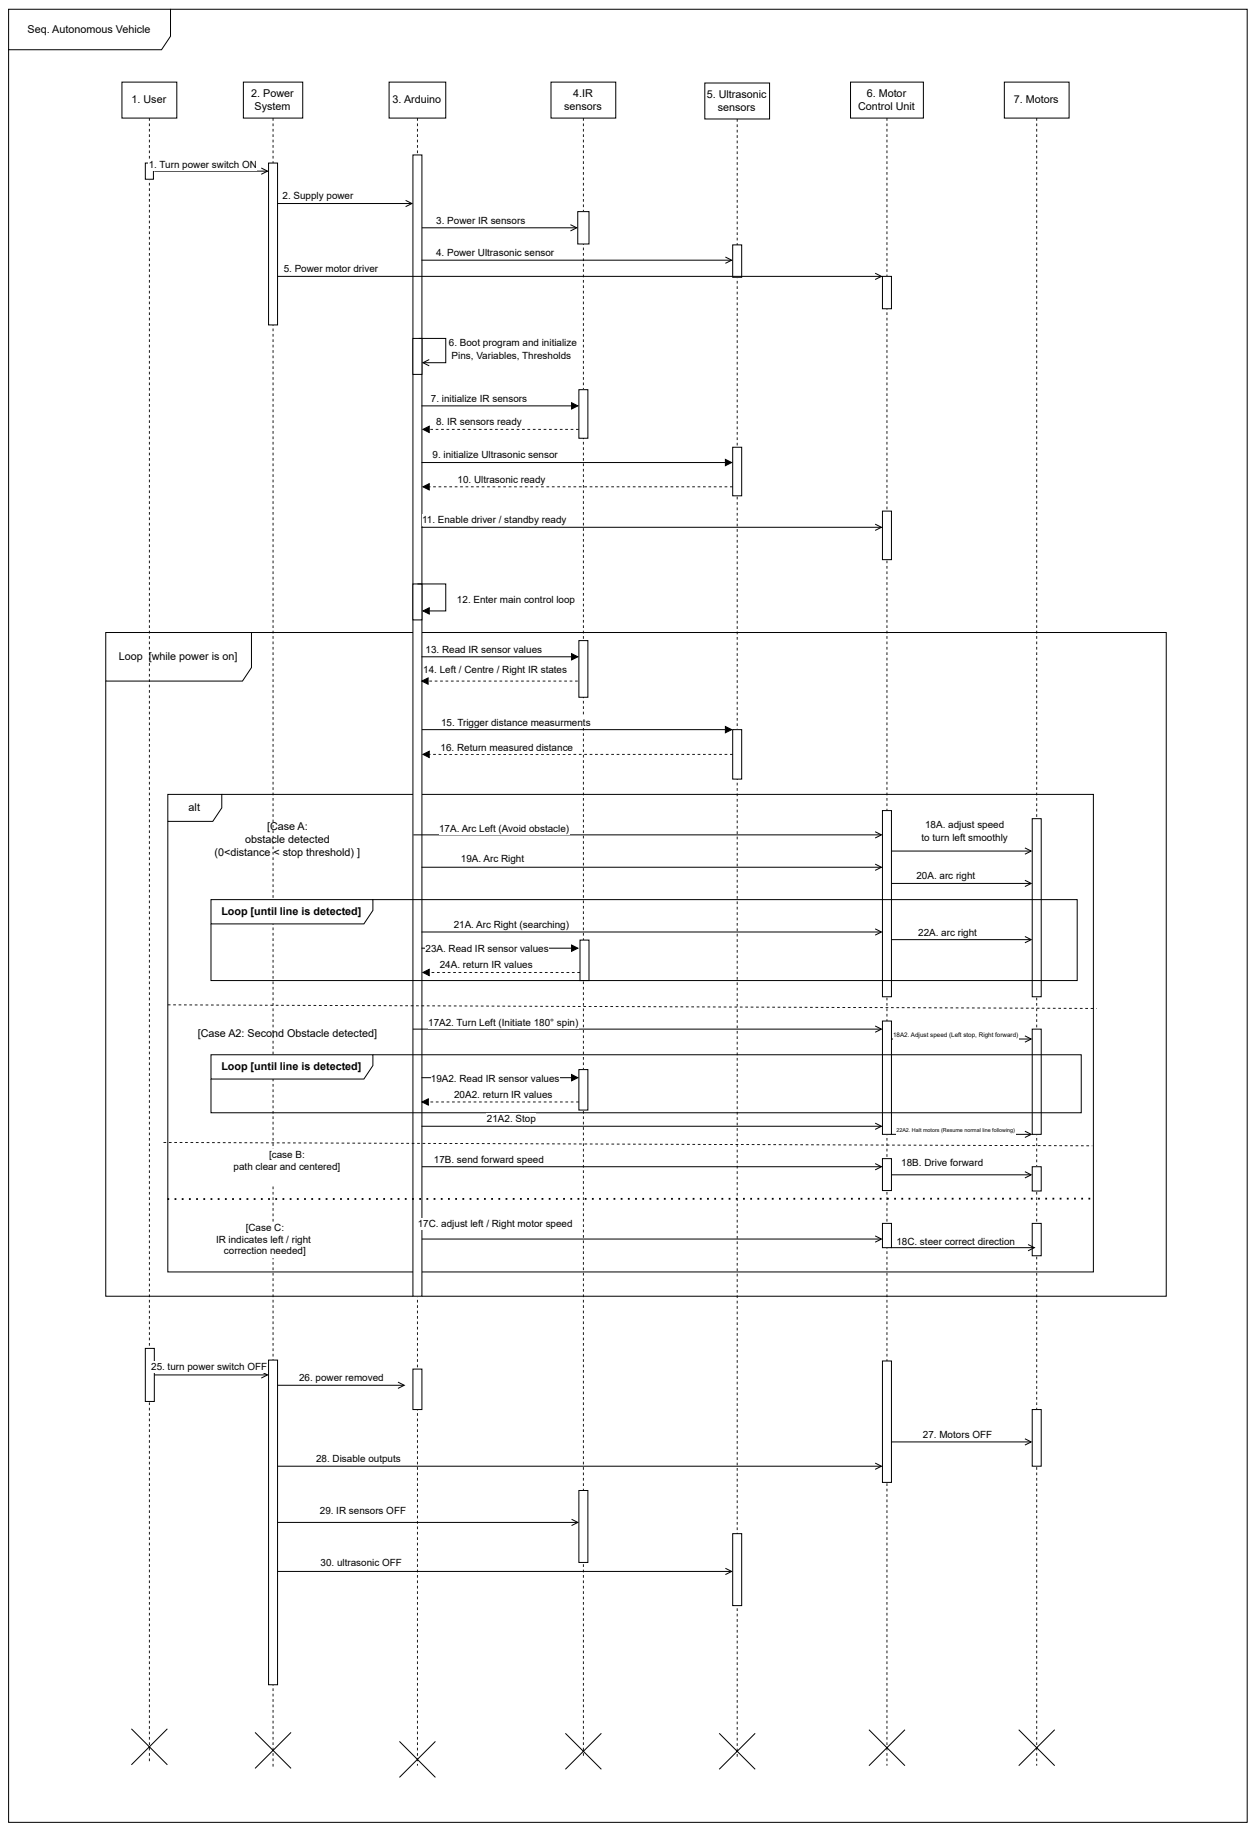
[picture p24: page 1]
1. User; 2. Power System; 3. Arduino; 4.IR sensors; 5. Ultrasonic sensors; 6. Motor Control Unit; 7. Motors; 2. Supply power; 10. Ultrasonic ready; [case B:; 26. power removed; 28. Disable outputs; 27. Motors OFF; 30. ultrasonic OFF; 17A. Arc Left (Avoid obstacle); 18A. adjust speed; 17B. send forward speed; 18B. Drive forward; 19A. Arc Right; 20A. arc right; 21A. Arc Right (searching); 22A. arc right

Seq. Autonomous Vehicle

1. Turn power switch ON

3. Power IR sensors

4. Power Ultrasonic sensor

5. Power motor driver

6. Boot program and initialize Pins, Variables, Thresholds

7. initialize IR sensors

8. IR sensors ready

9. initialize Ultrasonic sensor

11. Enable driver / standby ready

12. Enter main control loop

Loop [while power is on]

13. Read IR sensor values
14. Left / Centre / Right IR states

15. Trigger distance measurments

16. Return measured distance

alt [Case A: obstacle detected (0<distance < stop threshold) ]

to turn left smoothly

Loop [until line is detected]

23A. Read IR sensor values
24A. return IR values

[Case A2: Second Obstacle detected]

17A2. Turn Left (Initiate 180° spin)

18A2. Adjust speed (Left stop, Right forward)

19A2. Read IR sensor values
20A2. return IR values

21A2. Stop

22A2. Halt motors (Resume normal line following)

path clear and centered]

[Case C:
IR indicates left / right
correction needed]

17C. adjust left / Right motor speed

18C. steer correct direction

25. turn power switch OFF

29. IR sensors OFF

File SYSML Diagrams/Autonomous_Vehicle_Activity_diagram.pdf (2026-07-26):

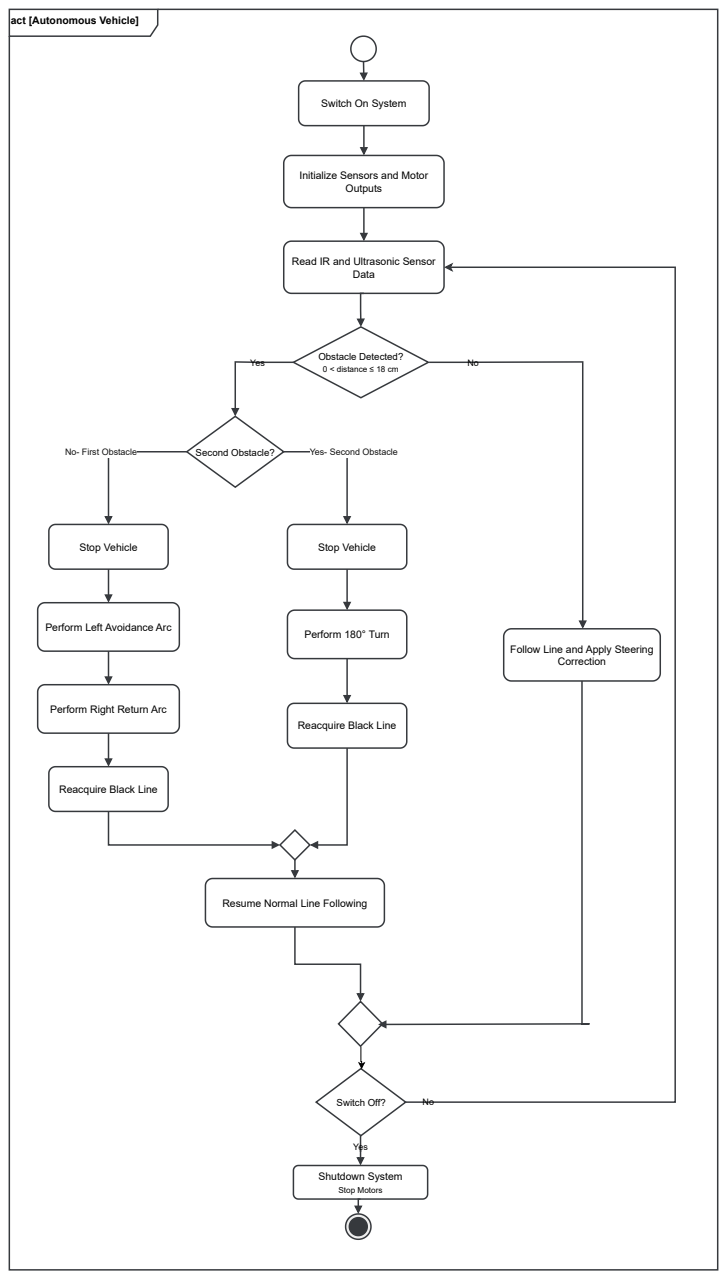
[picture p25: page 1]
Outputs; Data; Obstacle Detected? 0 < distance ≤ 18 cm; Correction; Second Obstacle?; Stop Vehicle; Perform 180° Turn; Switch Off?; Shutdown System; Stop Motors; Yes; No- First Obstacle; Yes- Second Obstacle

act [Autonomous Vehicle]

Switch On System

Initialize Sensors and Motor

Read IR and Ultrasonic Sensor

Perform Left Avoidance Arc

Follow Line and Apply Steering

Perform Right Return Arc

Reacquire Black Line

Resume Normal Line Following

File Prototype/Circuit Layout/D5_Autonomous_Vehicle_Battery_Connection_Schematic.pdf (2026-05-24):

A

1 | 2 | 3 | 4 | 5 | 6

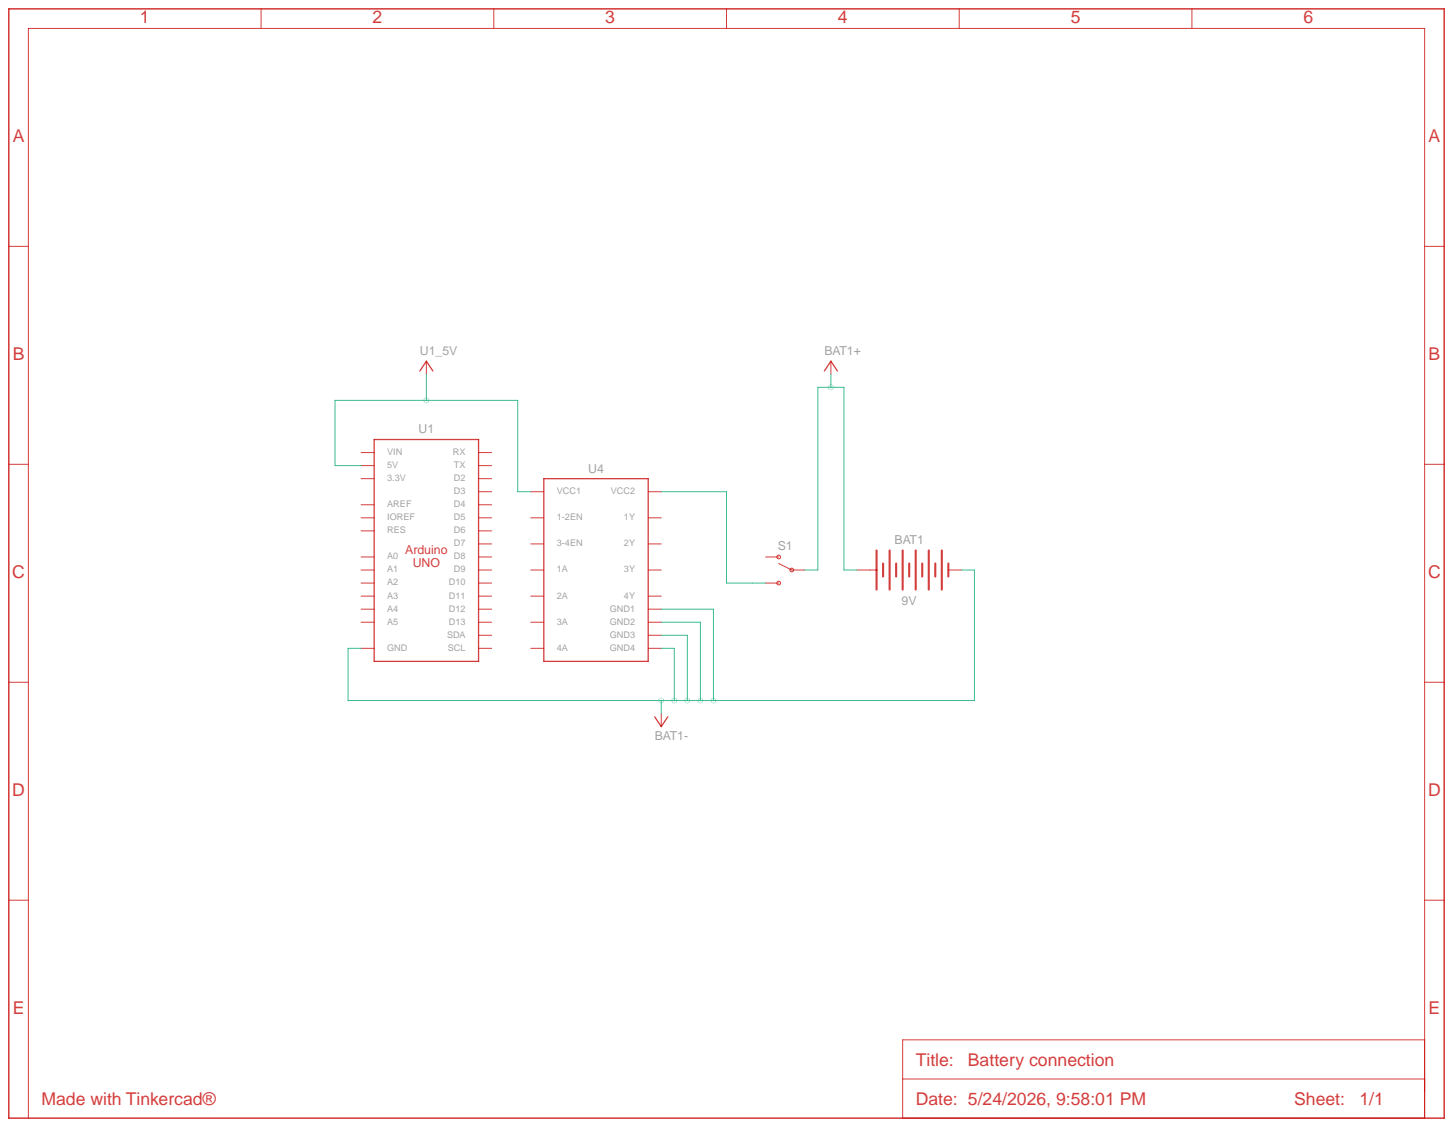
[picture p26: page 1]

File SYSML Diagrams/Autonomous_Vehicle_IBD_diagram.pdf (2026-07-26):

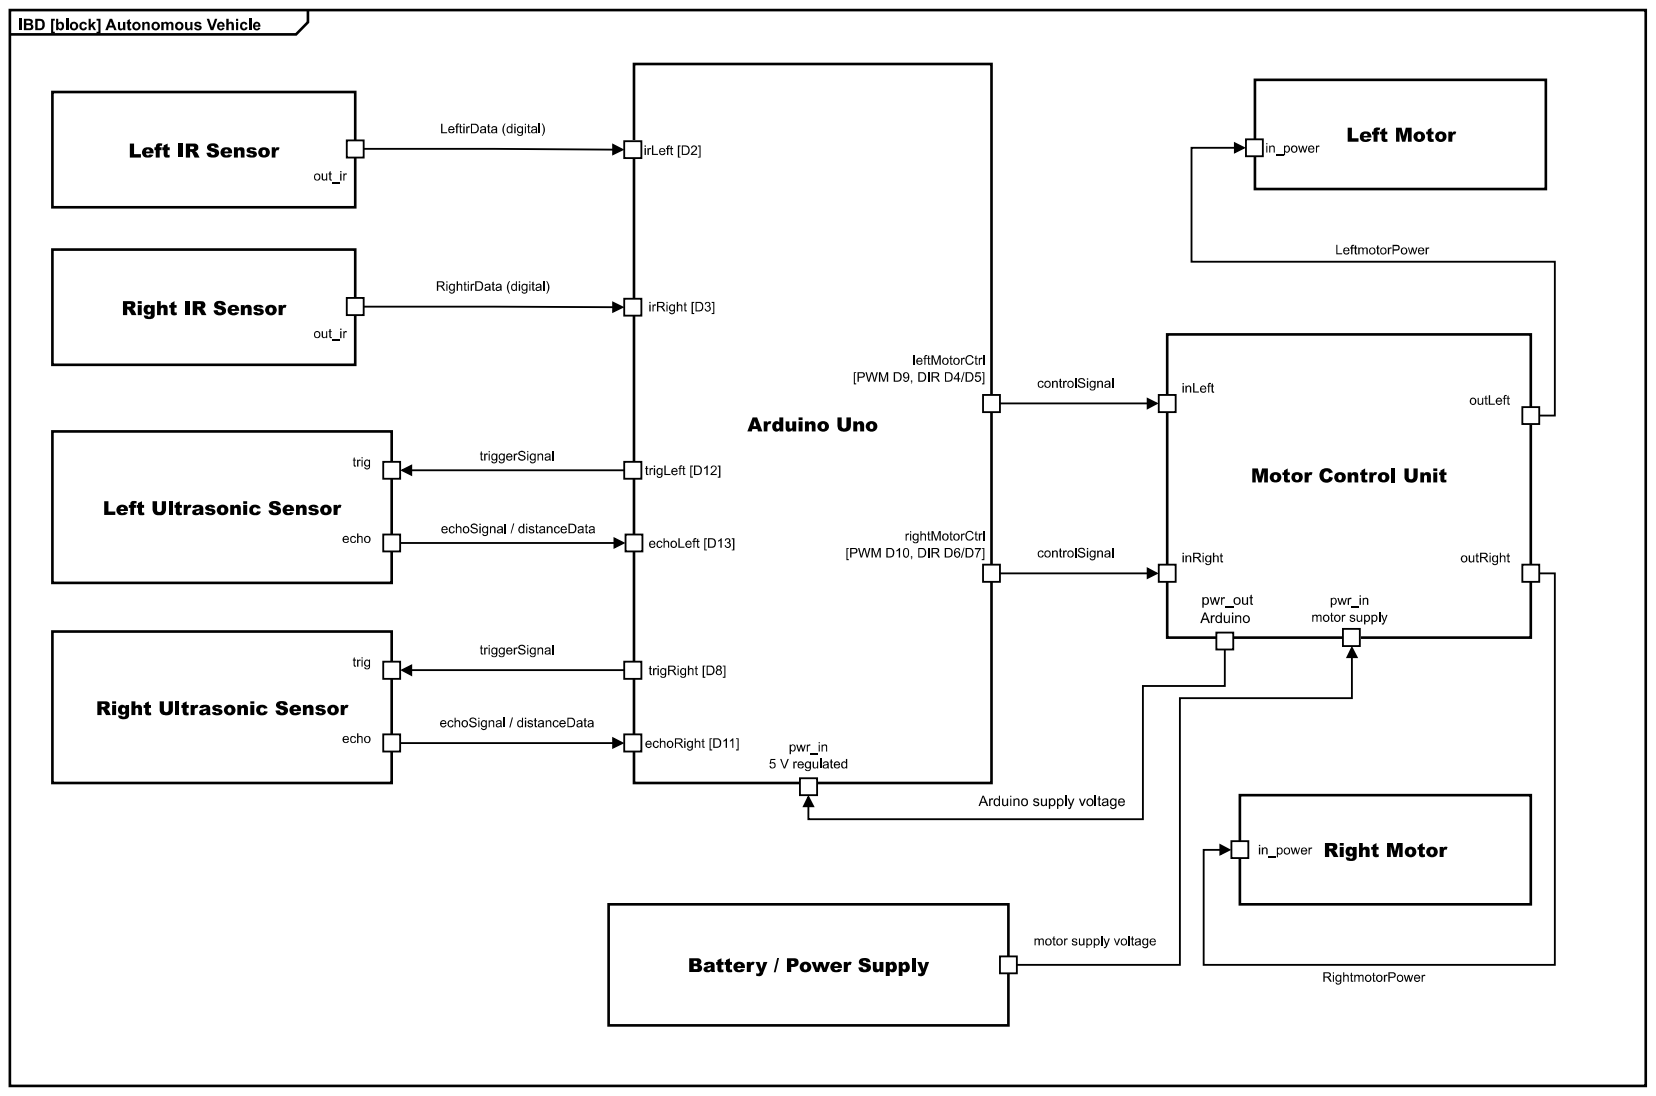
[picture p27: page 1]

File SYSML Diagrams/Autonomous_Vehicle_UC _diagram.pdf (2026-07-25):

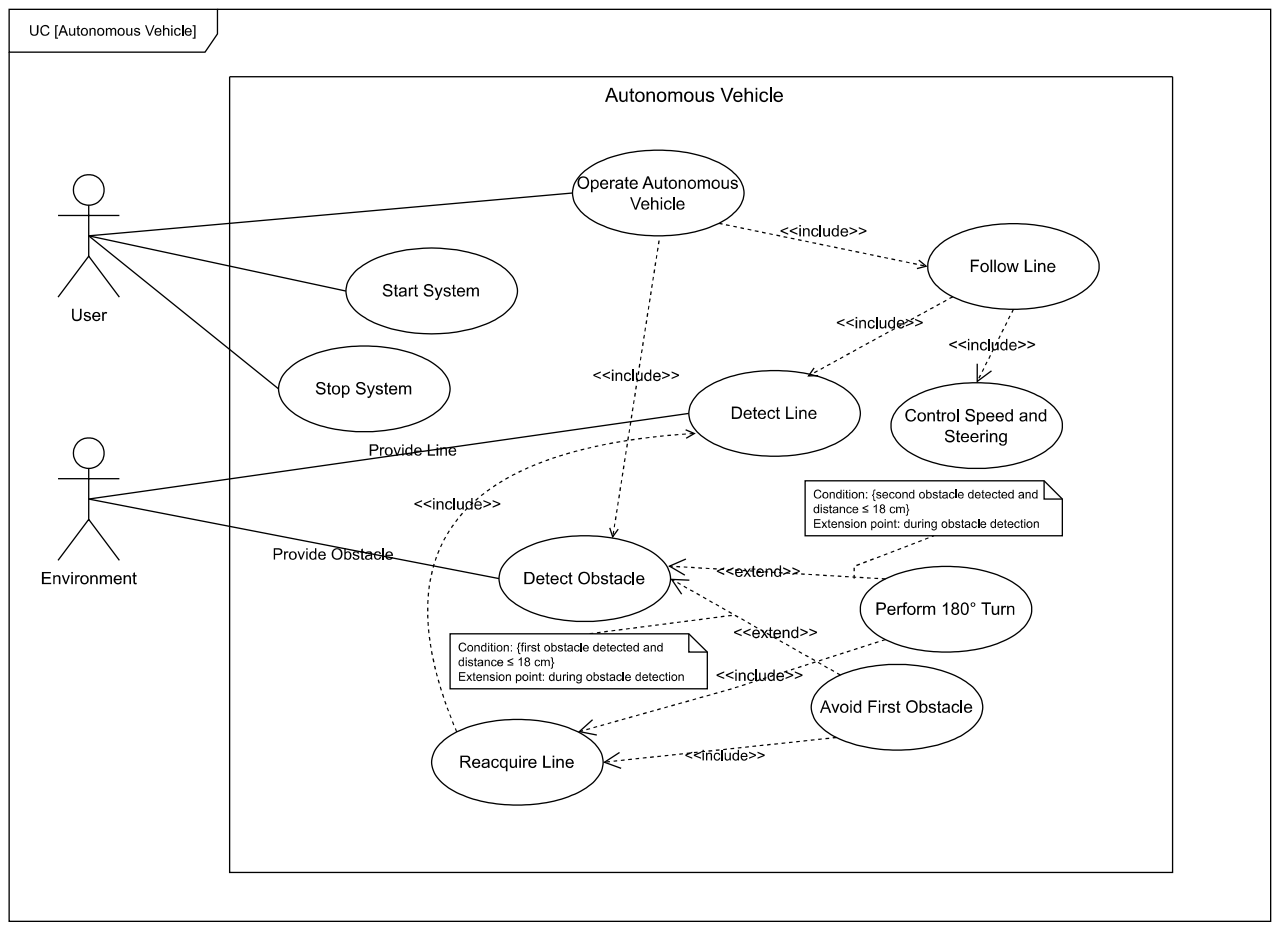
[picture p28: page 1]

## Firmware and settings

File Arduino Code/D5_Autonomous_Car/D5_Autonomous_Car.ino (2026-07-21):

// ─────────────────────────────────────
// UltrasonicSensor
// ─────────────────────────────────────
class UltrasonicSensor {
  int trig, echo;

public:
  UltrasonicSensor(int trig, int echo) : trig(trig), echo(echo) {}

  void begin() {
    pinMode(trig, OUTPUT);
    pinMode(echo, INPUT);
  }

  long getDistance() {
    digitalWrite(trig, LOW);
    delayMicroseconds(2);
    digitalWrite(trig, HIGH);
    delayMicroseconds(10);
    digitalWrite(trig, LOW);

    long duration = pulseIn(echo, HIGH, 6000);

    if (duration == 0) {
      return 0;
    }

    return duration * 0.034 / 2;
  }
};

// ─────────────────────────────────────
// IRSensor
// ─────────────────────────────────────
class IRSensor {
  int pin;

public:
  IRSensor(int pin) : pin(pin) {}

  void begin() {
    pinMode(pin, INPUT);
  }

  // TRUE = WHITE
  // FALSE = BLACK
  bool onLine() {
    return digitalRead(pin) == LOW;
  }
};

// ─────────────────────────────────────
// Motor
// ─────────────────────────────────────
class Motor {
  int en, in1, in2;

public:
  Motor(int en, int in1, int in2) : en(en), in1(in1), in2(in2) {}

  void begin() {
    pinMode(en,  OUTPUT);
    pinMode(in1, OUTPUT);
    pinMode(in2, OUTPUT);
  }

  void forward(int speed) {
    analogWrite(en, speed);
    digitalWrite(in1, HIGH);
    digitalWrite(in2, LOW);
  }

  void backward(int speed) {
    analogWrite(en, speed);
    digitalWrite(in1, LOW);
    digitalWrite(in2, HIGH);
  }

  void stop() {
    analogWrite(en, 0);
    digitalWrite(in1, LOW);
    digitalWrite(in2, LOW);
  }
};

// ─────────────────────────────────────
// Car
// ─────────────────────────────────────
class Car {
  Motor            leftMotor;
  Motor            rightMotor;
  IRSensor         leftIR;
  IRSensor         rightIR;
  UltrasonicSensor rightSonar;
  UltrasonicSensor leftSonar;

  // --- TUNING ---
  static const int SPEED      = 75;
  static const int TURN_SPEED = 43;
  static const int STOP_DIST  = 18;

  // Speeds for dodging LEFT
  static const int DODGE_ARC_SLOW = 10; 
  static const int DODGE_ARC_FAST = 80;

  // Speeds for sweeping RIGHT
  static const int RETURN_ARC_SLOW = 48; 
  static const int RETURN_ARC_FAST = 90; 

  // Arc timing
  static const int STOP_TIME      = 400;
  static const int LEFT_ARC_TIME  = 620;
  static const int RIGHT_ARC_TIME = 3500;

  unsigned long lastObstacleTime = 0;

  unsigned long turnStartTime = 0;
  bool isTurning = false;

  int obstacleCount = 0; 

  unsigned long lastSonarTime = 0;
  bool checkRightSonarNext = true;

  enum AvoidState {
    IDLE,
    STOP_BEFORE_OBSTACLE,
    LEFT_ARC_AROUND,
    RIGHT_ARC_BACK,
    SEARCH_LINE,
    RECOVER_LINE,
    TURN_180
  };

  AvoidState avoidState = IDLE;
  unsigned long avoidTimer = 0;

public:
  Car()
    : leftMotor (9,  4, 5)
    , rightMotor(10, 6, 7)
    , leftIR    (2)
    , rightIR   (3)
    , rightSonar(8, 11)
    , leftSonar (12, 13)
  {}

  void begin() {
    leftMotor.begin();
    rightMotor.begin();
    leftIR.begin();
    rightIR.begin();
    rightSonar.begin();
    leftSonar.begin();
    stop();
  }

  void update() {
    if (avoidState != IDLE) {
      handleObstacleAvoidance();
      return;
    }

    if (millis() - lastSonarTime > 30) {
      lastSonarTime = millis();

      long distRight = 0;
      long distLeft = 0;

      if (checkRightSonarNext) {
        distRight = rightSonar.getDistance();
      } else {
        distLeft = leftSonar.getDistance();
      }

      checkRightSonarNext = !checkRightSonarNext;

      bool obstacleRight = (distRight > 0 && distRight <= STOP_DIST);
      bool obstacleLeft  = (distLeft  > 0 && distLeft  <= STOP_DIST);

      // Only count if we haven't seen an obstacle in the last 2 seconds
      if ((obstacleRight || obstacleLeft) && (millis() - lastObstacleTime > 2000)) {
        stop();
        lastObstacleTime = millis();

        obstacleCount++;

        if (obstacleCount >= 2) {
          avoidState = TURN_180;
        } else {
          avoidState = STOP_BEFORE_OBSTACLE;
        }

        avoidTimer = millis();
        isTurning = false;
        return;
      }
    }

    followLine(); 
  }

private:
  void driveForward() {
    leftMotor.forward(SPEED);
    rightMotor.forward(SPEED);
  }

  void turnLeft() {
    leftMotor.stop();
    rightMotor.forward(SPEED);
  }

  void turnRight() {
    leftMotor.forward(SPEED);
    rightMotor.stop();
  }

  void spinLeft() {
    leftMotor.backward(TURN_SPEED);
    rightMotor.forward(SPEED);
  }

  void spinRight() {
    leftMotor.forward(SPEED);
    rightMotor.backward(TURN_SPEED);
  }

  void stop() {
    leftMotor.stop();
    rightMotor.stop();
  }

  void arcLeft() {
    leftMotor.forward(DODGE_ARC_SLOW);
    rightMotor.forward(DODGE_ARC_FAST);
  }

  void arcRight() {
    leftMotor.forward(RETURN_ARC_FAST);
    rightMotor.forward(RETURN_ARC_SLOW);
  }

  bool blackLineDetected() {
    return !leftIR.onLine() || !rightIR.onLine();
  }

  // ─────────────────────────────────────
  // Normal line following
  // ─────────────────────────────────────
  void followLine() {
    bool L = leftIR.onLine();  // true = WHITE, false = BLACK
    bool R = rightIR.onLine(); // true = WHITE, false = BLACK

    if (L && R) {
      driveForward();
      isTurning = false;
    }

    else if (!L && R) {
        spinLeft();
    }

    else if (L && !R) {
        spinRight();
    }

    else {
      spinLeft();
      isTurning = false;
    }
  }

  // ─────────────────────────────────────
  // Obstacle avoidance:
  // stop → left arc → right arc → find line
  // ─────────────────────────────────────
  void handleObstacleAvoidance() {
    unsigned long elapsed = millis() - avoidTimer;

    switch (avoidState) {

      case STOP_BEFORE_OBSTACLE:
        stop();

        if (elapsed > STOP_TIME) {
          avoidState = LEFT_ARC_AROUND;
          avoidTimer = millis();
        }
        break;

      case LEFT_ARC_AROUND:
        {
          long currentDist = rightSonar.getDistance();

          if (currentDist > 0 && currentDist < 10) { 
            spinLeft(); 
          } else {
            arcLeft();  
          }

          if (elapsed > LEFT_ARC_TIME) {
            avoidState = RIGHT_ARC_BACK;
            avoidTimer = millis();
          }
        }
        break;

      case RIGHT_ARC_BACK:
        arcRight();

        if (elapsed > 150 && blackLineDetected()) {
          
          // 1. CROSS THE LINE: 
          // Let the motors keep running arcRight() for a fraction of a second 
          // so the car completely crosses over into the white space on the other side.
          delay(250); 
          
          // 2. SPIN LEFT:
          spinLeft();
          
          // 3. LOOP UNTIL IT HITS THE LINE:
          // Keep looping as long as NO black line is detected (both sensors see white).
          // The exact millisecond a sensor touches black, the loop breaks.
          while (!blackLineDetected()) {
          }
          
          // 4. STOP AND RECOVER:
          stop();
          delay(250); // Brief pause to let the chassis settle before driving forward
          
          avoidState = RECOVER_LINE;
          avoidTimer = millis();
          break;
        }
        
        // Failsafe in case it completely misses the line on the way back
        if (elapsed > 5000) {
          avoidState = SEARCH_LINE;
          avoidTimer = millis();
        }
        break;

      case SEARCH_LINE:
        arcRight();

        // When line is detected again from ANY sensor, spin left to adjust
        if (blackLineDetected()) {
          delay(250); 
          
          // 2. SPIN LEFT:
          spinLeft();
          
          // 3. LOOP UNTIL IT HITS THE LINE:
          // Keep looping as long as NO black line is detected (both sensors see white).
          // The exact millisecond a sensor touches black, the loop breaks.
          while (!blackLineDetected()) {
          }
          
          // 4. STOP AND RECOVER:
          stop();
          delay(250); // Brief pause to let the chassis settle before driving forward
          
          avoidState = RECOVER_LINE;
          avoidTimer = millis();
          break;
        }

        if (elapsed > 6000) {
          stop();
        }
        break;

        case TURN_180:
         turnLeft();
         obstacleCount = 0;

        if (elapsed > 1400 && blackLineDetected()) {
          stop();
          delay(400);     

          avoidState = RECOVER_LINE;
          avoidTimer = millis();
          isTurning = false;
          break;
        }

      case RECOVER_LINE:
        followLine();
        avoidState = IDLE;
        break;

      case IDLE:
        break;
    }
  }
};

// ─────────────────────────────────────
// Main
// ─────────────────────────────────────
Car car;

void setup() {
  Serial.begin(9600);
  car.begin();

  unsigned long startTime = millis();
  while (millis() - startTime < 2000) {}
}

void loop() {
  car.update();
}

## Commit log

2026-05-24 Rename D5 - Motor Holder.STEP to D5 - Motor Holder Right.STEP
    [D5 - Motor Holder Right.STEP]
2026-05-24 Rename D5 - ultrasonic holder final.STEP to D5 - Ultrasonic Holder.STEP
    [D5 - Ultrasonic Holder.STEP]
2026-05-24 Rename D5 - BATTERY AND BREAD BOARD HOLDER.STEP to D5 - Battery and Breadboard Holder.STEP
    [D5 - Battery and Breadboard Holder.STEP]
2026-05-24 Rename D5 - wires track.STEP to D5 - Wires Track.STEP
    [D5 - Wires Track.STEP]
2026-05-24 Add info file with car assembly photos
2026-06-24 Swap IR sensor assignments and adjust turning logic
2026-06-27 Refactor ultrasonic sensor and obstacle avoidance logic
    Updated ultrasonic sensor timeout and obstacle avoidance logic. Adjusted speed constants and added new states for improved navigation.
2026-07-02 Update sonar pulse duration timeout
    Reduced sonar pulse duration timeout from 15000us to 3000us.
2026-07-02 Add Ultrasonic, IR, and Motor classes for Car control
2026-07-03 Adjust timing and speed parameters in ultrasonic code
2026-07-21 Rename Arduino Code/D5_Autonomous_Car.ino to Arduino Code/D5_Autonomous_Car/D5_Autonomous_Car.ino
2026-07-21 Rename Autonomous Vehicle Circuit Schematic.pdf to D5_Autonomous_Vehicle_Circuit_Schematic.pdf
2026-07-21 Rename Battery Connection Schematic.pdf to D5_Autonomous_Vehicle_Battery_Connection_Schematic.pdf
2026-07-21 Rename Autonomous Vehicle TinkerCAD Assembly Design.png to D5_Autonomous_Vehicle_TinkerCAD Assembly_Design.png
2026-08-15 Update project title from 'Prototype Car' to 'Vehicle'
